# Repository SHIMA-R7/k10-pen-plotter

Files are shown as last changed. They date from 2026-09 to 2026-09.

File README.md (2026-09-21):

# K10 Pen Plotter

EasyThreed K10 (メイン基板 **K10 V2.1**) を、**純正基板のまま** Marlin 2.1.2.8 で動くペンプロッタに改造したプロジェクトです。
外付けのマイコンやモータードライバは使わず、基板上の GD32F303 と HR4988 をそのまま使います。

*Convert an EasyThreed K10 mini 3D printer into a pen plotter using its stock mainboard (GD32F303CBT6 + HR4988) and a custom Marlin 2.1.2.8 build.*

| 本体 | 描画結果 | ペンリフト (CAD) |
|---|---|---|
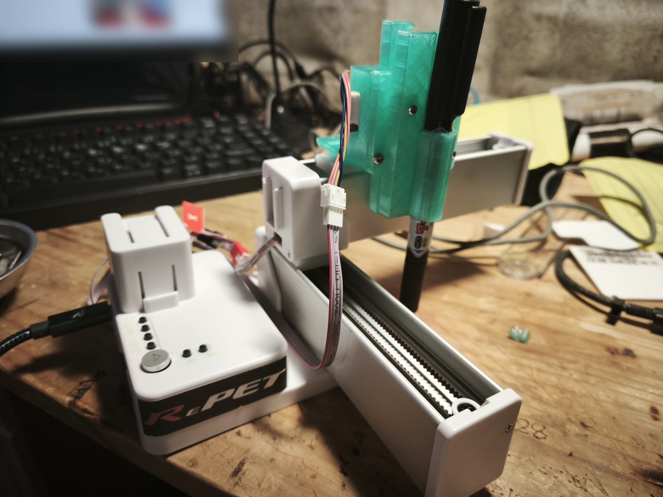
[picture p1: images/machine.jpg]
machine
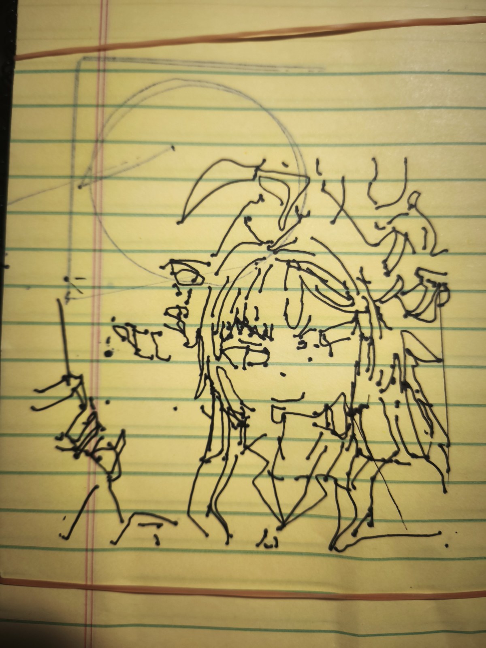
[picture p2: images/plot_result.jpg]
result
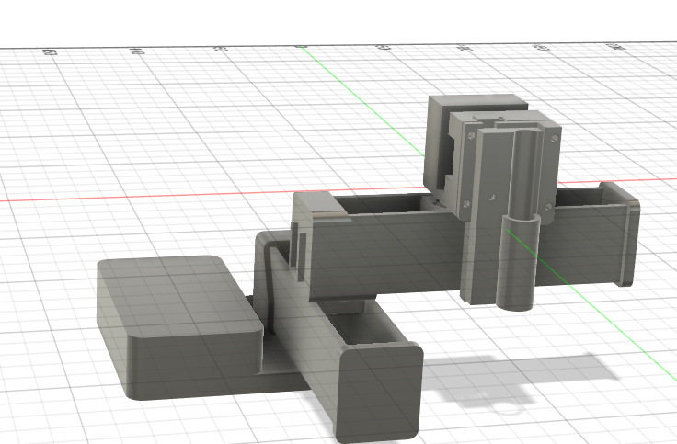
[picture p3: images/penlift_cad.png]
cad
|  |  |  |

## 構成

| 軸 | 用途 | コネクタ | 備考 |
|---|---|---|---|
| X | ペン左右 | X (赤) | 606 steps/mm (純正値、実測確認済) |
| Y | 紙 (ベッド) 前後 | Y (黒) | 606 steps/mm |
| Z (論理) | ペン上下 | **E (白)** | 押出機のドライバを流用。24BYJ/28BYJ 系ギヤードステッパ + ラック&ピニオン、649 steps/mm |
| (Z) | ガントリ昇降 | Z (青) | 使わない (高さ固定、モーターは外す) |

- 描画範囲 90 × 90 mm
- 原点センサーなし。**X/Y を機構の「奥」側の端に押し当てた位置** (ペン先 = 紙の右手前の角) を基準にする
- PC との通信なし。SD カードの `plot.gco` を本体のボタンで描画する

## ハードウェア

- 基板: EasyThreed K10 V2.1 — MCU **GD32F303CBT6** (LQFP48, 128KB), ドライバ **HR4988SQ ×4**
  - 引き継ぎ情報では「GD32F103」とされていたが、実物の刻印は GD32F303CBT6 だった
- ペンリフト: [hardware/penlift](hardware/penlift)
  - `stl/` : 最終版 (V1.0) の印刷データ
  - `gears/` : ピニオン (m1, z16, 軸 φ5 2面カット) とラックの STEP と生成スクリプト
  - モーター: 24BYJ28 系 12V ギヤードステッパ (4線バイポーラで E コネクタへ)
  - フローティングペン: ラックはペンを持ち上げるだけで、下ろしたときはペンが自重で紙に乗る
- SWD 書き込み: Raspberry Pi Pico を [debugprobe](https://github.com/raspberrypi/debugprobe) にして使用
  - 基板の SD スロット横の 2×3 ヘッダ: 1 = SWDIO, 2 = 3V3, 3 = SWCLK, 4 = GND, 5 = NRST, 6 = VSSA
  - 配線: ヘッダ1 → Pico GP3, ヘッダ3 → Pico GP2, ヘッダ4 → GND (3V3 はつながない。K10 側は自前の電源で動かす)

## ピン配置 (純正ファームの解析結果)

純正ファームを SWD でダンプし、静的解析 + 動作中のレジスタ監視 (動的解析) で特定しました。詳細は [docs/pinmap.md](docs/pinmap.md)、MCU の図は [docs/mcu_pinout.svg](docs/mcu_pinout.svg)。

| 信号 | ピン |
|---|---|
| X STEP / DIR | PC15 / PC14 |
| Y STEP / DIR | PC13 / PA8 |
| Z (ガントリ) STEP / DIR | PA9 / PA10 |
| E STEP / DIR | PA11 / PA12 |
| EN (4ドライバ共通, Low で有効) | PB9 |
| モーター電流 VREF (PWM 約19.2kHz) | PB5, PB6, PB7, PB8 |
| ヒーター / ファン / サーミスタ | PB3 / PB4 (PWM) / PA2 |
| ボタン ▷ / S3 S4 S6 S7 S8 S9 | PB10 / PB0 PB1 PB12 PB13 PB14 PB15 |
| SD (SPI1) CS / 挿入検出 | PA4 / PA3 |
| ステータス LED | PA1 |

注意点:
- **USB-C にデータ線は来ていない** (PA11/PA12 は E のドライバ)。UART1 (PA9/PA10) も Z ドライバに使われている
- **VREF は MCU の PWM + RC で作っている**。ファームで PWM を出さないとモーターは動かず、High 固定だと約4A 設定になり危険
- 4つのドライバの EN は共通

## 使い方

### ファームウェアを書く
1. Pico を debugprobe 化し、SWD ヘッダに配線する
2. (推奨) 純正ファームをバックアップ: `tools/swd/dump.ps1` (フラッシュ128KB を2回読んで照合)
3. 書き込み: `tools/swd/flash_marlin.ps1` (ビルド済み `firmware/prebuilt/k10_plotter_marlin.bin` を 0x08004000 へ。純正の SD ブートローダは残る)
4. 戻すとき: `tools/swd/restore_stock.ps1 -Image <バックアップ>`

OpenOCD は [xPack OpenOCD](https://github.com/xpack-dev-tools/openocd-xpack) を使用 (PATH に置くか環境変数 `OPENOCD` にフルパス)。
自分でビルドする場合は [firmware/README.md](firmware/README.md)。

### 描く
1. 電源 OFF の状態で、X と Y を「奥」側の端まで手で押し当てる (ペン先 = 紙の右手前の角)
2. 電源 ON。S8 / S9 でペン先をちょうど紙に触れる位置まで下げ、下げる方向にもう1回押す (フローティングの余裕)
3. ▷ を押す → その位置を X90 Y0 Z0 として、SD カードのルートの `plot.gco` を描画。終わるとペンを上げて開始位置へ戻る

| ボタン | 動作 |
|---|---|
| ▷ | 現在位置を X90 Y0 Z0 にして `plot.gco` を描画 |
| S3 / S4 | X −5 / +5 mm |
| S6 / S7 | Y −5 / +5 mm |
| S8 / S9 | Z (ペン) +0.5 / −0.5 mm |

### 描画データを作る
[plots/](plots) のスクリプトを使います ([vpype](https://github.com/abey79/vpype) + vpype-gcode が必要)。

```bash
# 線画ビットマップ → センターライン SVG (輪郭の二重線にならない)
python plots/img2svg_centerline.py 画像.jpg -o 画像.svg
# SVG → K10 用 G-code (最大 90mm 角、ペン上げ Z7 / 下げ Z0、プレビュー PNG と所要時間も出力)
python plots/svg2k10.py 画像.svg -s 90 -o plot.gco
```

G-code の座標は X0..90 / Y0..90 (X+ = 紙に対して右、Y+ = 紙に対して奥)、ペン下げ `Z0`、ペン上げ `Z7`。

## ハマりどころ (記録)

- **Y とペンの軸の向き**: `INVERT_X_DIR true` / `INVERT_Y_DIR false` / `INVERT_Z_DIR false` が実機で正しかった。Y はベッドが動くので「紙から見たペンの動き」はベッドの動きと逆になる
- **脱調**: 50mm/s・加速度1000 では「ピロリリ」と鳴って脱調。20mm/s・300mm/s² に下げて解決
- **Marlin 2.1.2.8 の不具合 (STM32 / EXTRUDERS 0)** — `firmware/apply_k10.py` でパッチ
  - M907 のレポートで `SP_E_STR` 未定義
  - ユーザーボタンの初期化が AVR 流で、STM32 ではプルアップが効かない
  - `EXTRUDERS 0` だと `MOTOR_CURRENT_PWM_E_PIN` が消されるので、4本目の VREF は `MOTOR_CURRENT_PWM_XY_PIN` で出す
- **Marlin の既定タイマ**: STEP=TIM4 は VREF PWM (TIM4) と衝突するので STEP_TIMER=1 / TEMP_TIMER=2
- **vpype の `read`** は既定でページ境界で切り取るので、図とページが同寸だと縁の辺が消える → `--no-crop`
- ネット上の「K10 V2.1 = GD32F103 / MKS Robin Lite 互換」という情報は、この個体には当てはまらなかった

## 参考

- palmarci: [EasyThreed K10 3D printer main board reversing](https://palmarci.me/blog/2025-05-02-easythreed-k10-3d-printer-main-board-reversing/index.html)
- [Marlin Firmware](https://marlinfw.org/)
- [HR4988 データシート (Heroic)](https://www.heroic.com.cn/en/product/motor/motor1/hr4988-150.html)

## ライセンス

GPL-3.0 ([LICENSE](LICENSE))。ファームウェアは Marlin (GPL-3.0) の派生物です。
EasyThreed の純正ファームウェアはこのリポジトリに含まれていません。

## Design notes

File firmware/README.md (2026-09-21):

# ファームウェアのビルド

素の **Marlin 2.1.2.8** に、このフォルダの設定とパッチを当ててビルドします。

| ファイル | 内容 |
|---|---|
| `apply_k10.py` | Configuration.h / Configuration_adv.h の変更、Marlin 本体の小パッチ2件、ピン定義と env の追加を行う。元ファイルは `.orig` に退避され、何度実行しても同じ結果になる |
| `pins_custom.h` | K10 V2.1 のピン定義 (`BOARD_CUSTOM` で読み込まれる) |
| `buttons_block.h` | 本体ボタンの G-code (`CUSTOM_USER_BUTTONS`) |
| `env_k10.ini` | PlatformIO の env (`custom`)。0x08004000 に配置 |
| `prebuilt/k10_plotter_marlin.bin` | ビルド済みバイナリ |

## 手順

```bash
# 1. Marlin 2.1.2.8 を取得して展開 (パスに日本語やスペースを含まない場所で)
#    https://github.com/MarlinFirmware/Marlin/archive/refs/tags/2.1.2.8.zip
# 2. 設定を適用
python apply_k10.py path/to/Marlin-2.1.2.8
# 3. ビルド
cd path/to/Marlin-2.1.2.8
pio run -e custom
# → .pio/build/custom/firmware.bin を tools/swd/flash_marlin.ps1 -Bin で書き込む
```

## PlatformIO のダウンロードが遅い場合

PlatformIO レジストリのミラーが極端に遅い環境 (約20KB/s) では、以下を GitHub から取得してローカルパッケージにできます。

| パッケージ | 取得元 |
|---|---|
| toolchain-gccarmnoneeabi | xPack arm-none-eabi-gcc 9.2.1-1.1 |
| framework-arduinoststm32 | stm32duino/Arduino_Core_STM32 1.9.0 |
| framework-cmsis | ARM-software/CMSIS_5 5.5.1 |

- それぞれのフォルダに `package.json` (`name` と `version`: 1.90201.191206 / 4.10900.200819 / 2.50501.200527) を置く
- `framework-arduinoststm32/CMSIS` を `framework-cmsis` へのジャンクション (リンク) にする
- CMSIS_5 の `CMSIS/DSP/Lib/GCC/libarm_cortexM3l_math.a` は Git LFS のポインタなので、空のアーカイブ (`!<arch>\n`) に置き換える
- `env_k10.ini` の `platform_packages` と `custom_gcc` のコメントを外してパスを書き換える

## 主な設定値

- 軸: X = PC15/PC14, Y = PC13/PA8, Z (ペン) = PA11/PA12 (E コネクタ), EN = PB9
- steps/mm: X 606, Y 606, Z 649 / 最大速度 20, 20, 6 mm/s / 加速度 300, 300, 100 mm/s²
- 向き: `INVERT_X_DIR true`, `INVERT_Y_DIR false`, `INVERT_Z_DIR false`
- モーター電流: PB5/PB6/PB7/PB8 に PWM 19.2kHz、800mA 相当 (デューティ 19.2%)。`MOTOR_CURRENT_PWM_RANGE 4125`
- `EXTRUDERS 0`, ヒーター (PB3) は起動時に Low 固定
- シリアル: `SERIAL_PORT 1` (PA9/PA10 = 未使用のガントリ Z ドライバの線。外部には出ていない)
- ソフトウェアエンドストップ無効 (原点センサーなし)

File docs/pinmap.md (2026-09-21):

# K10 V2.1 (GD32F303CBT6) ピンマップ — 純正ファーム解析結果

出典: SWDダンプ `dump/k10_flash_1.bin` (SHA256 BE649BF4…9E93) の静的解析 + 動作中のRAM/レジスタ読み出し (2026-09-21)

## フラッシュ構成
| 範囲 | 内容 |
|---|---|
| 0x08000000–0x08003FFF | SDブートローダ (`1:/p10_printer.bin` → 書込後 `P10_PRINTER.CUR` にリネーム) |
| 0x08004000–0x0801CE96 | 純正アプリ (~102KB) |
| 0x0801F800–0x0801F8C7 | 設定領域 (`k10_cfg.txt` 由来) |
- 読み出し保護なし (OB 0x5AA5)。フラッシュ128KB。
- 純正はGD32標準ライブラリ直叩き。GPIOは RAM上の表 (port 0x20000754 / mask 0x2000079c, 18項目) 経由。

## ⚠ 実機確認 (2026-09-21): 純正内部の軸順とコネクタのシルクは Y/E が逆
| コネクタ (シルク) | STEP | DIR | 純正内部の軸 |
|---|---|---|---|
| X (赤) | PC15 | PC14 | X |
| Y (黒) | PA11 | PA12 | E |
| Z (青) | PA9 | PA10 | Z |
| E (白) | PC13 | PA8 | Y |
下の表は「純正内部の軸名」で書いてある。Marlin 設定 (pins_custom.h) はコネクタ基準で修正済み。

## ステッパ (HR4988SQ ×4) — 純正ファーム内部の軸名
| 軸 | STEP | DIR | EN | 純正 INVERT_DIR | 純正 steps/mm |
|---|---|---|---|---|---|
| X | PC15 | PC14 | PB9 | 1 | 606 |
| Y | PC13 | PA8  | PB9 | 1 | 606 |
| Z | PA9  | PA10 | PB9 | 1 | 600 |
| E | PA11 | PA12 | PB9 | 1 | 1040 |
- EN は4ドライバ共通、Lowで有効。起動時は High(無効)。
- 根拠: stepper init (0x0800B280) が表の奇数idxを STEP として Low、DIR設定 (0x0800AD64) が軸0..3 に偶数idx を使用。HWテスト (0x0801B5C2/0x0801B634) も同じ組分け。
- PA9/PA10(UART1)、PA11/PA12(USB) はステッパに使用済み → USB-Cはデータ非対応、UART1も使えない。

## モーター電流 VREF (PWM, 要注意)
| ピン | タイマ | 純正デューティ | VREF | 電流 (Rs=0.1Ω) |
|---|---|---|---|---|
| PB5 | TIMER2_CH1 (部分リマップ) | 145/750 | 0.64V | 約0.80A |
| PB6 | TIMER3_CH0 | 145/750 | 0.64V | 約0.80A |
| PB7 | TIMER3_CH1 | 127/750 | 0.56V | 約0.70A |
| PB8 | TIMER3_CH2 | 127/750 | 0.56V | 約0.70A |
- PSC=4, CAR=749 → 約19.2kHz。RCで平滑して HR4988 REF へ入ると推定。
- どのピンがどの軸かは未確定 (PB5,6=X,Y / PB7,8=Z,E と推定)。ドライバREF(17番)からの導通で確認する。
- **ファームでこのPWMを出さないとモーターは動かない。High固定だと VREF=3.3V → 約4A設定で危険。**

## その他
| ピン | 設定 | 推定用途 |
|---|---|---|
| PA2 | アナログ入力 | サーミスタ (TH) — 表idx10 |
| PB3 | 出力 (起動時Low) | **ヒーター** — 温度ISRの7bitソフトPWM (`cmp #0x7f`, 0x080126D6)、全ヒーター停止で0書込 (0x08012660)。表idx11 |
| PB4 | TIMER2_CH0 PWM (0%) | **ファン (動的解析で確定)**: M106 S128 で CV0 0→5019 (印刷中の周期10000)、S255 で10000、M107 で0 |
| PA1 | 出力 | ステータスLED — 状態に応じて速/遅点滅・点灯 (0x08012E30) |
| PA15 | 出力 (起動時High、以後不変) | 不明。ドライバ SLEEP/RESET 解除の可能性大 → 要導通確認。Marlinでも起動時Highにする |
| PA3 | 入力プルアップ | SDカード検出 (Lowで挿入、起動時マウント判定 0x0801B592 / 0x080086FA) |
| PB10 | 入力プルアップ | **表面の大きな ▷ (印刷開始) ボタン** (動的解析で確定) |
| PB0 / PB1 / PB12 / PB13 / PB14 / PB15 | 入力プルアップ | **裏面 S3 / S4 / S6 / S7 / S8 / S9** (動的解析で確定、押下で Low) |
| PA4 | 出力 (High) | SD CS |
| PA5/PA6/PA7 | SPI0 | SD SCK/MISO/MOSI |
| PA13/PA14 | SWD | ヘッダ 1=SWDIO, 3=SWCLK, 2=3V3, 4=GND, 5=NRST, 6=VSSA |
| PA0, PB2, PB11 | 未使用 (フローティング入力) | 空きピン候補 |
- AFIO: JTAG無効/SWD有効 (PA15/PB3/PB4 解放)、TIMER2 部分リマップ。
- エンドストップ入力に該当するものは見当たらない。

## 動的解析 (2026-09-21, k10\dynamic)
- SD の `K10TEST.gcode` を純正ファームで実行し、OpenOCD の TCL ポート経由で CPU を止めずにレジスタを監視
- ファン/ボタンは上表のとおり確定
- `M104 S45` で純正の `kill()` (0x08007610) に入り停止。サーミスタ ADC = 0xFCA (開放状態) → MINTEMP。ヒーター PB3 の動的確認と M17/M18 は未実施
- 純正ファームは `.GCO` 拡張子のファイルを実行、`G28` を使う (エンドストップなしの突き当て原点と推定)

## 純正の運動パラメータ (RAMから)
- max feedrate 候補: X/Y 3000, Z 240, E 60 (mm/min)

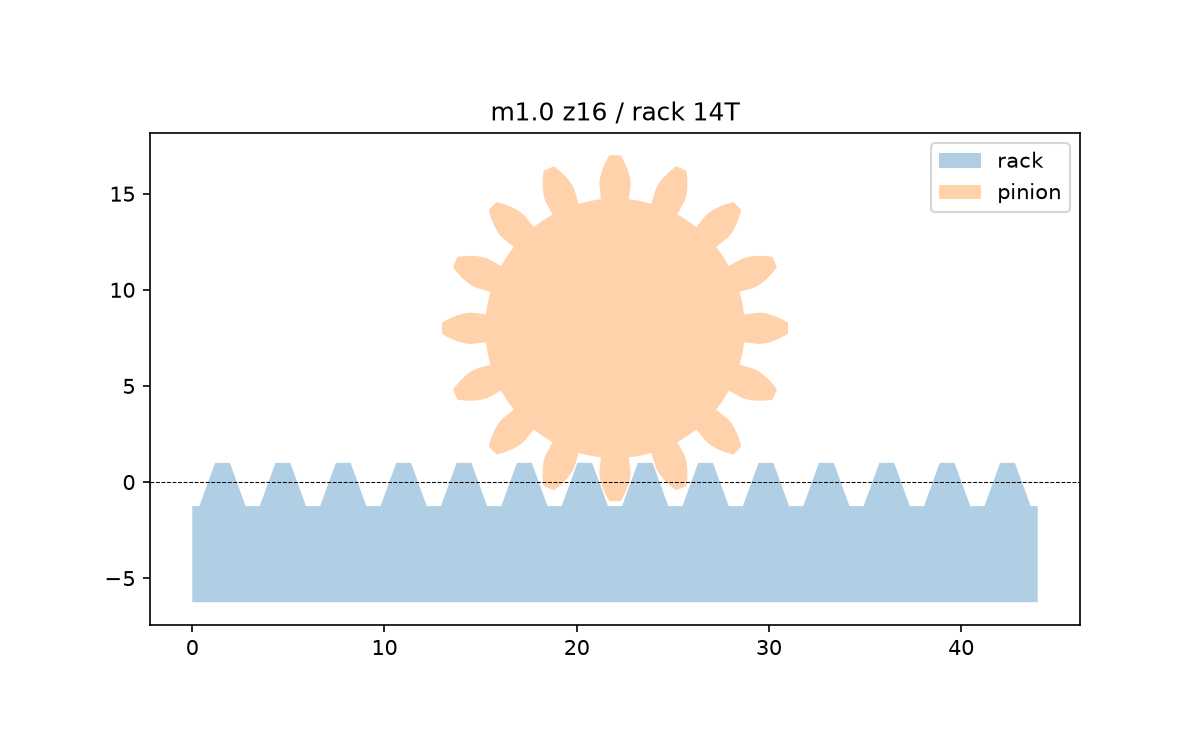
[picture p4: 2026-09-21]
hardware/penlift/gears/check.png

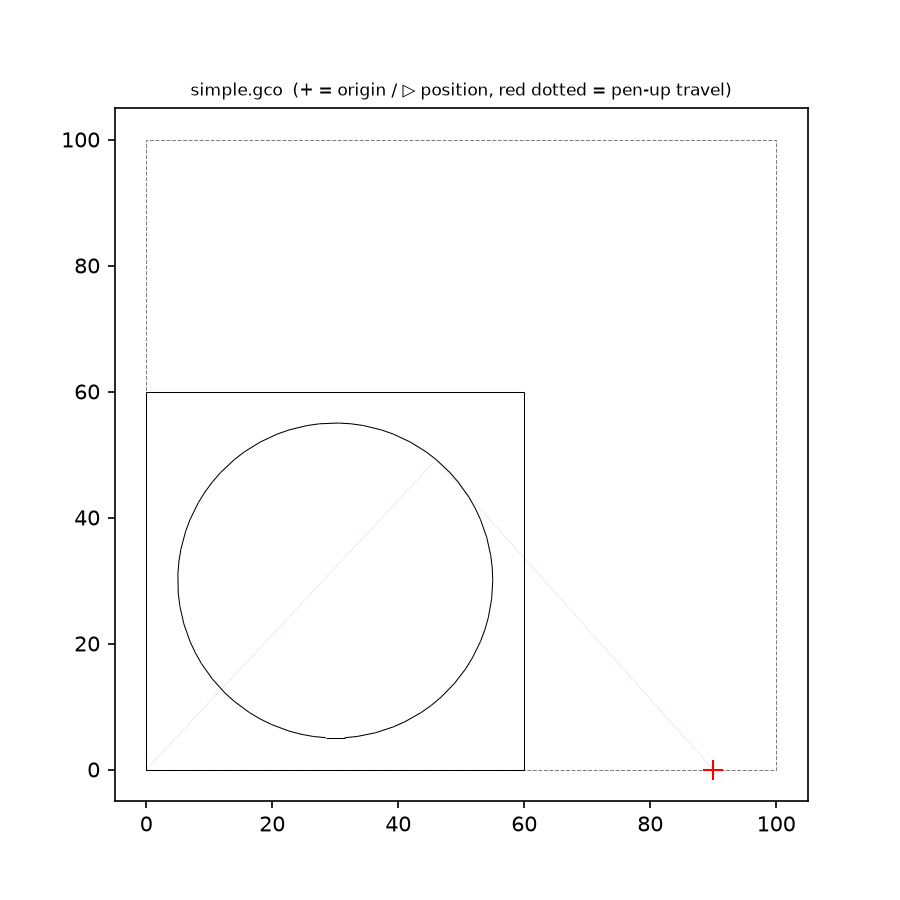
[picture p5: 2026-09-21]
plots/simple.png

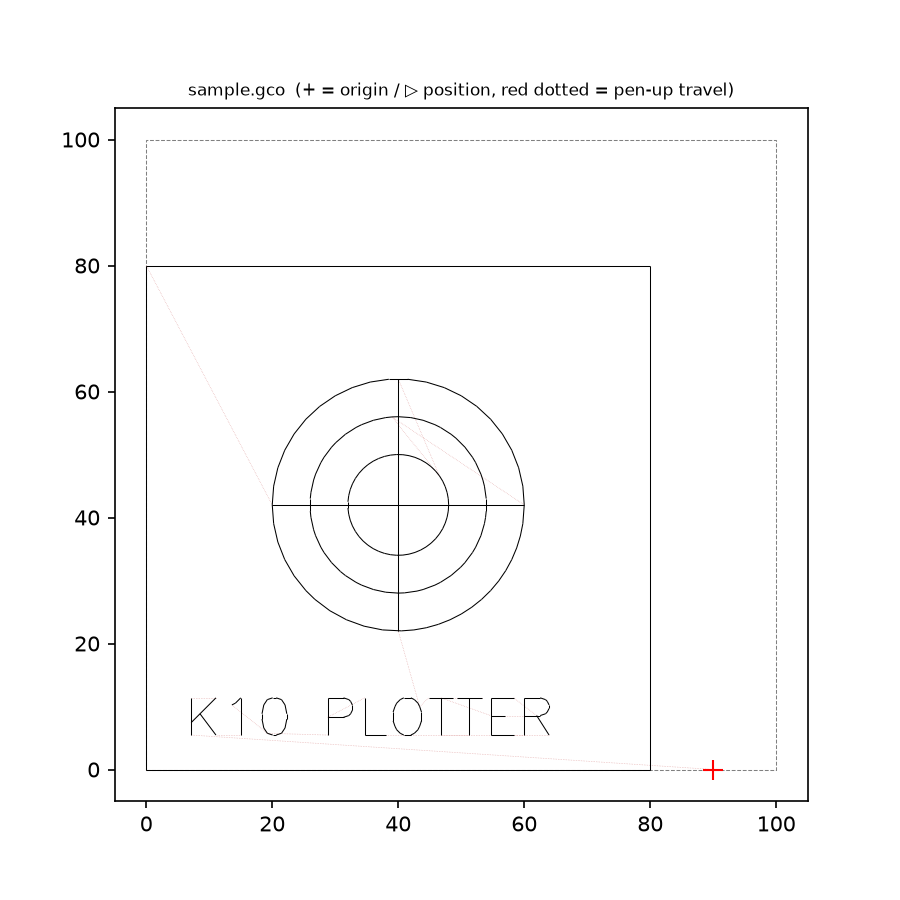
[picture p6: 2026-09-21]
plots/sample.png

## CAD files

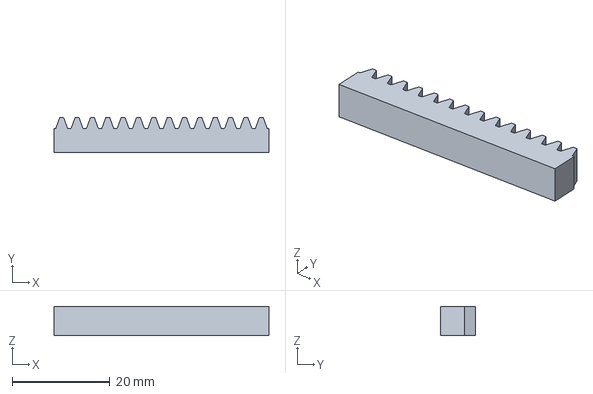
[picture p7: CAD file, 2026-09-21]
hardware/penlift/gears/rack.step
44.0 x 7.25 x 6.00 mm

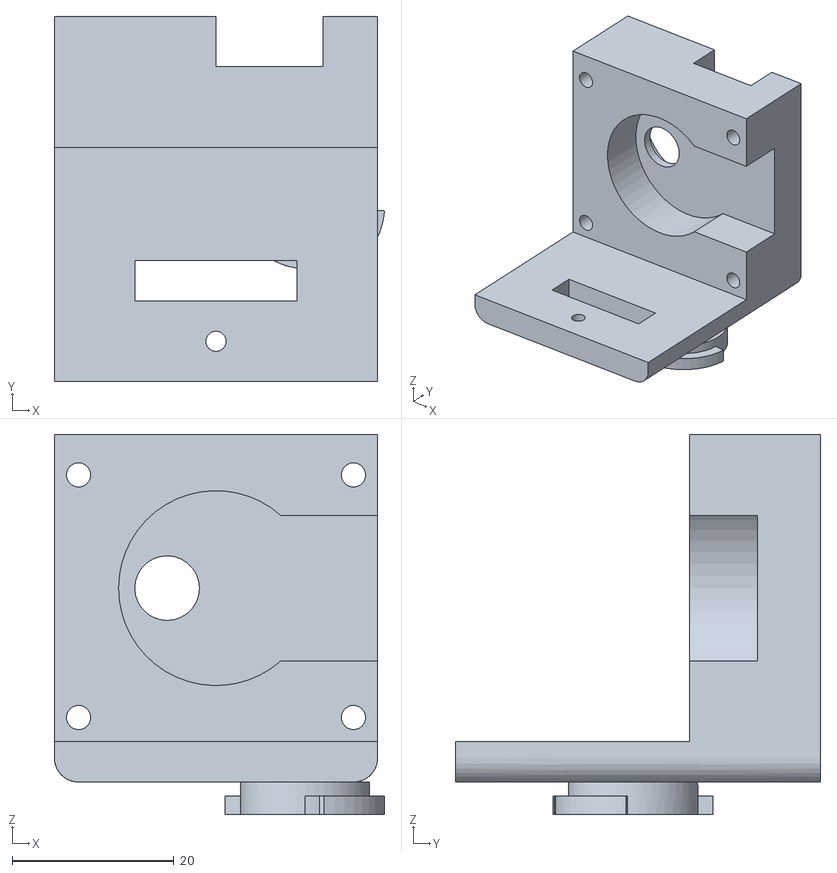
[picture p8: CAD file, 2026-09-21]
hardware/penlift/stl/pen_base.stl
40.9 x 45.2 x 47.0

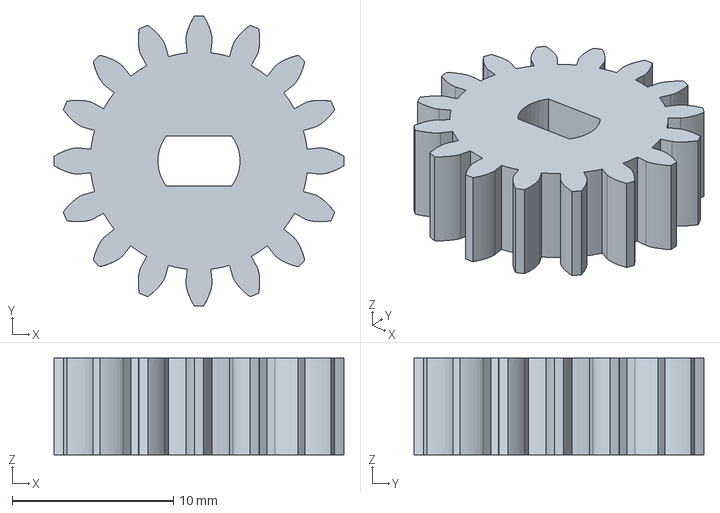
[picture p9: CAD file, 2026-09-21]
hardware/penlift/gears/pinion.step
18.0 x 18.0 x 6.00 mm

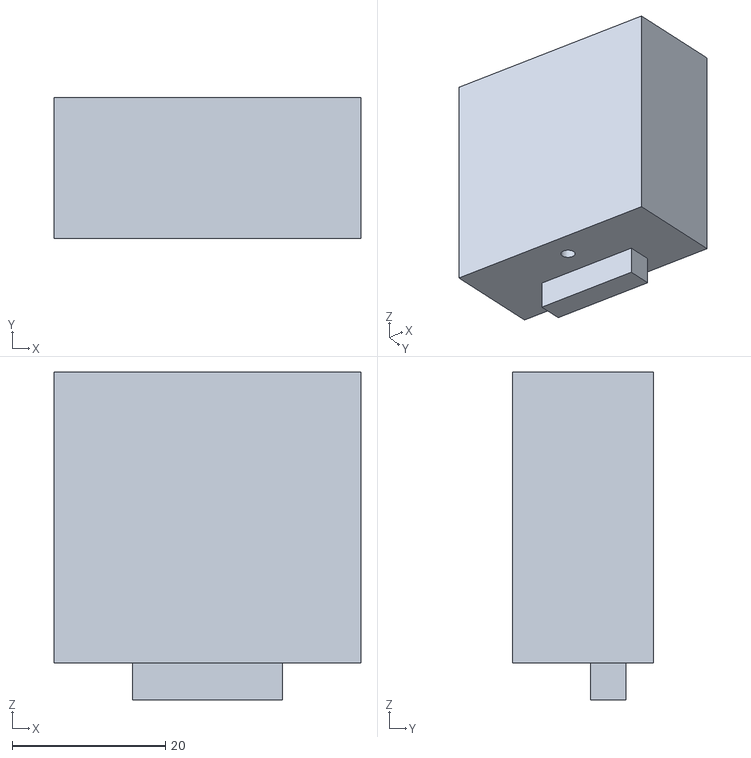
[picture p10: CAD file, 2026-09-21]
hardware/penlift/stl/motor_mount.stl
40.0 x 18.4 x 42.8

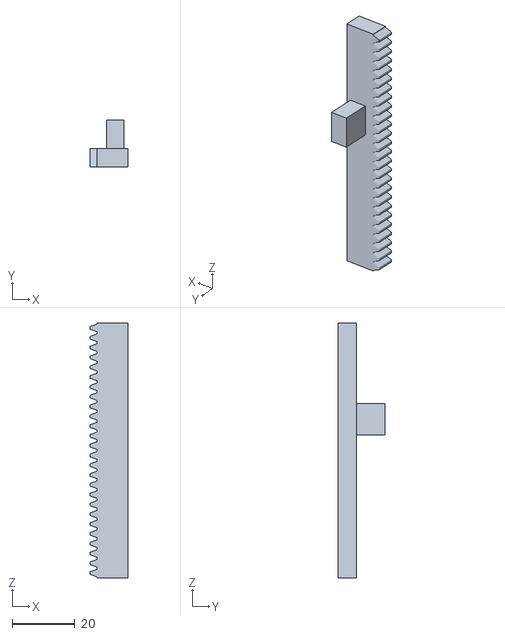
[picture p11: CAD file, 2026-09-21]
hardware/penlift/stl/rack.stl
12.3 x 15.2 x 81.6

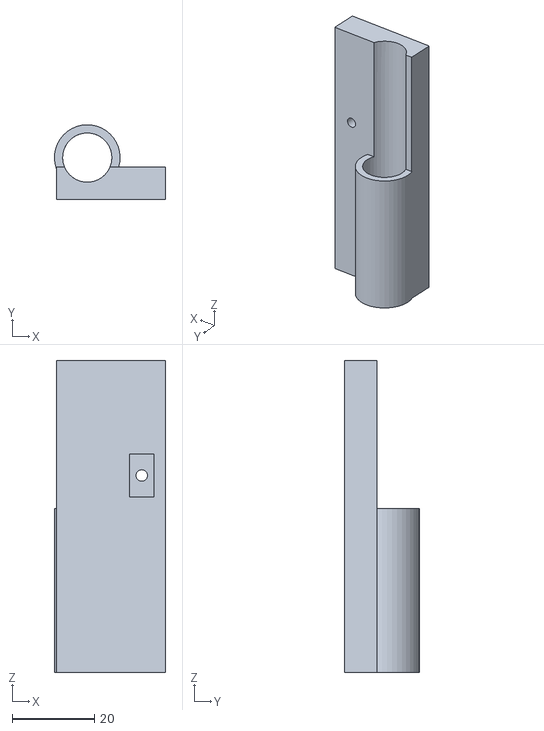
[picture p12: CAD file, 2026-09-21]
hardware/penlift/stl/pen_rack.stl
27.1 x 18.2 x 76.0

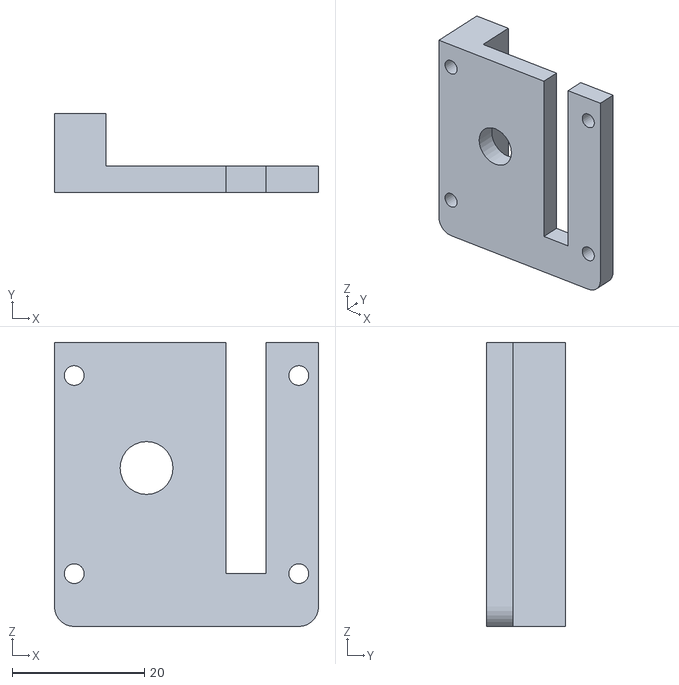
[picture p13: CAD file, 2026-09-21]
hardware/penlift/stl/rack_cover.stl
40.0 x 12.0 x 43.0

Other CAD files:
hardware/penlift/stl/pinion.stl

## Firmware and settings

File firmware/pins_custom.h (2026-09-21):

/**
 * EasyThreed K10 V2.1 (GD32F303CBT6 LQFP48, HR4988SQ x4)
 * 純正ファームのSWDダンプ解析 + 実機レジスタ読み出しで特定したピン定義。
 * 解析メモ: docs/pinmap.md
 *
 * GD32F303CB を STM32F103CB として動かす (ステッパ用 PA9-PA12 は USB/UART と共用のため、USB/UART1 は使えない)
 */
#pragma once

#define BOARD_INFO_NAME      "EasyThreed K10 V2.1"
#define DEFAULT_MACHINE_NAME "K10 Plotter"

#define BOARD_NO_NATIVE_USB

// 外部EEPROMなし → フラッシュ末尾をEEPROM代わりに使う
#define FLASH_EEPROM_EMULATION

// Marlin 既定の STEP=TIM4 / TEMP=TIM2 は VREF PWM (TIM4: PB6-PB8) と衝突するので変更
#define STEP_TIMER 1
#define TEMP_TIMER 2

// JTAG を無効化 (SWD は残す) → PA15 / PB3 / PB4 を GPIO として使う
#define DISABLE_JTAG

//
// 起動直後に安全側へ固定する
//   PB3  ヒーター MOSFET → Low (常時 OFF)
//   PB4  ファン PWM     → Low
//   PA15 用途未確定 (純正は起動時 High にして以後不変。ドライバ SLEEP/RESET 解除と推定)
//   PA1  ステータス LED → 点灯
//   (ボタンの内部プルアップは apply_k10.py で MarlinCore.cpp の初期化マクロを修正して有効化)
//
#define BOARD_PREINIT() do{ \
  __HAL_RCC_AFIO_CLK_ENABLE(); \
  __HAL_AFIO_REMAP_SWJ_NOJTAG(); \
  OUT_WRITE(PB3, LOW);  \
  OUT_WRITE(PB4, LOW);  \
  OUT_WRITE(PA15, HIGH); \
  OUT_WRITE(PA1, HIGH); \
}while(0)

//
// Steppers (純正ファームの stepper init 0x0800B280 / DIR 設定 0x0800AD64 で確認)
//   純正ファーム内部の軸順 (X,Y,Z,E) どおり。シルクとも一致 (2026-09-21 実機で確認: ケーブルは正しく
//   刺さった状態で PC13/PA8 → Y モーター、PA11/PA12 → 押出機モーターが動いた)
//   コネクタ   STEP  DIR
//   X (赤)     PC15  PC14
//   Y (黒)     PC13  PA8    ← ベッド前後
//   Z (青)     PA9   PA10   ← ガントリ昇降。プロッタでは使わない (高さ固定)
//   E (白)     PA11  PA12   ← 押出機モーターを流用してペン上下にする
//   EN は4ドライバ共通 PB9 (Low で有効)
//
// プロッタ構成: Marlin の論理 Z 軸 = ペン上下 = E(白) コネクタのドライバ
//
#define X_STEP_PIN                          PC15
#define X_DIR_PIN                           PC14
#define X_ENABLE_PIN                        PB9

#define Y_STEP_PIN                          PC13
#define Y_DIR_PIN                           PA8
#define Y_ENABLE_PIN                        PB9

#define Z_STEP_PIN                          PA11   // E(白) コネクタ (ペン)
#define Z_DIR_PIN                           PA12
#define Z_ENABLE_PIN                        PB9

//
// Motor current (HR4988 VREF を PWM + RC で生成)
// 純正: 約19.2kHz, PB5/PB6 = 145/750, PB7/PB8 = 127/750
// 100% デューティ = 3.3V → Itrip = 3.3 / (8 * 0.1Ω) ≈ 4125mA を RANGE とすると純正と同じデューティになる
//   800mA → 19.2%, 700mA → 16.9%
// !! VREF ピンとドライバの対応は未確認 (導通確認待ち)。STEP/DIR 同様に Y/E が入れ替わっている可能性もあるので、
//    確定するまでは4本すべてに純正 X/Y と同じ 800mA 相当 (19.2%) を出して、どのドライバにも確実に電流が流れるようにする。
//    EXTRUDERS 0 だと MOTOR_CURRENT_PWM_E_PIN は pins_postprocess.h で消されるので、
//    4本目 (PB7) は XY グループの予備ピン MOTOR_CURRENT_PWM_XY_PIN として出す。
//    M907 X<mA> → PB5/PB6/PB7、M907 Z<mA> → PB8
//
#define MOTOR_CURRENT_PWM_X_PIN             PB5
#define MOTOR_CURRENT_PWM_Y_PIN             PB6
#define MOTOR_CURRENT_PWM_XY_PIN            PB7
#define MOTOR_CURRENT_PWM_Z_PIN             PB8
#define MOTOR_CURRENT_PWM_RANGE             4125
#define MOTOR_CURRENT_PWM_FREQUENCY         19200
#ifndef DEFAULT_PWM_MOTOR_CURRENT
  #define DEFAULT_PWM_MOTOR_CURRENT { 800, 800, 0 }   // XY(PB5,PB6,PB7), Z(PB8), E(なし) (mA)
#endif

//
// Endstops: K10 にはエンドストップ入力がない。空きピン(PA0/PB2/PB11)を仮に割り当てる
//
#define X_STOP_PIN                          PA0
#define Y_STOP_PIN                          PB2
#define Z_STOP_PIN                          PB11

//
// Temperature (プロッタでは未使用。定義だけ残す)
//
#define TEMP_0_PIN                          PA2
#define HEATER_0_PIN                        PB3
#define FAN0_PIN                            PB4

//
// Status LED
//
#define LED_PIN                             PA1

//
// SD card (SPI1: PA5 SCK / PA6 MISO / PA7 MOSI)
//
#define SD_DETECT_PIN                       PA3
#define SD_SS_PIN                           PA4
#define SD_SCK_PIN                          PA5
#define SD_MISO_PIN                         PA6
#define SD_MOSI_PIN                         PA7
#define SDSS                                SD_SS_PIN
#define SD_DETECT_STATE                     LOW

//
// 裏面ボタン S3-S9 (入力プルアップ)。どのボタンがどのピンかは動的解析で確定する
//   PB0, PB1, PB10, PB12, PB13, PB14, PB15
//

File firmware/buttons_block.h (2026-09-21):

#define CUSTOM_USER_BUTTONS
#if ENABLED(CUSTOM_USER_BUTTONS)
  // K10 V2.1 のボタン (動的解析で確定)。押下で Low
  //   ▷ = PB10 / 裏面 S3 = PB0, S4 = PB1, S6 = PB12, S7 = PB13, S8 = PB14, S9 = PB15
  // ペン機構: ラック&ピニオン + フローティングペン (戻しバネなし)。Z0 = ペン下げ / Z7 = ペン上げ
  // 使い方: 電源OFFで X/Y を「奥」側の端まで手で押し当てる (ペン先 = 紙の右手前の角) → 電源ON →
  //         S8/S9 でペン先をちょうど紙に乗る位置へ → ▷ で その位置を X90 Y0 Z0 にして SD の plot.gco を描画開始
  //         (描画範囲は X0..90 / Y0..90。X+ = 紙に対して右、Y+ = 紙に対して奥 が前提)

  #define BUTTON1_PIN           PB10      // ▷ 描画開始
  #define BUTTON1_HIT_STATE     LOW
  #define BUTTON1_WHEN_PRINTING false
  #define BUTTON1_GCODE         "G92 X90 Y0 Z0\nM23 plot.gco\nM24"
  #define BUTTON1_DESC          "Plot"

  #define BUTTON2_PIN           PB0       // S3: X -5mm
  #define BUTTON2_HIT_STATE     LOW
  #define BUTTON2_WHEN_PRINTING false
  #define BUTTON2_GCODE         "G91\nG0 X-5 F600\nG90"
  #define BUTTON2_DESC          "X-"

  #define BUTTON3_PIN           PB1       // S4: X +5mm
  #define BUTTON3_HIT_STATE     LOW
  #define BUTTON3_WHEN_PRINTING false
  #define BUTTON3_GCODE         "G91\nG0 X5 F600\nG90"
  #define BUTTON3_DESC          "X+"

  #define BUTTON4_PIN           PB12      // S6: Y -5mm
  #define BUTTON4_HIT_STATE     LOW
  #define BUTTON4_WHEN_PRINTING false
  #define BUTTON4_GCODE         "G91\nG0 Y-5 F600\nG90"
  #define BUTTON4_DESC          "Y-"

  #define BUTTON5_PIN           PB13      // S7: Y +5mm
  #define BUTTON5_HIT_STATE     LOW
  #define BUTTON5_WHEN_PRINTING false
  #define BUTTON5_GCODE         "G91\nG0 Y5 F600\nG90"
  #define BUTTON5_DESC          "Y+"

  #define BUTTON6_PIN           PB14      // S8: Z +0.5mm (ペン上げ方向)
  #define BUTTON6_HIT_STATE     LOW
  #define BUTTON6_WHEN_PRINTING false
  #define BUTTON6_GCODE         "G91\nG0 Z0.5 F300\nG90"
  #define BUTTON6_DESC          "Pen up"

  #define BUTTON7_PIN           PB15      // S9: Z -0.5mm (ペン下げ方向)
  #define BUTTON7_HIT_STATE     LOW
  #define BUTTON7_WHEN_PRINTING false
  #define BUTTON7_GCODE         "G91\nG0 Z-0.5 F300\nG90"
  #define BUTTON7_DESC          "Pen down"
#endif
